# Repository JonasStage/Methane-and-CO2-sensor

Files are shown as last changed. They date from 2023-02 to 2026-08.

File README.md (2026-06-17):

# CH<sub>4</sub> and CO<sub>2</sub> DIY sensor with automated aeration

This repository is dedicated to CH<sub>4</sub> and CO<sub>2</sub> sensors created by Jonas Stage Sø, for more information see [(Sø et al., 2024)](https://doi.org/10.1029/2024JG008035) and [(Sø et al., 2023)](https://doi.org/10.1016/j.scitotenv.2023.162895).  
Sensors are made following [Bastviken et al. (2020)](https://doi.org/10.5194/bg-17-3659-2020), modified for automated fluxes, higher resolution, and lower power consumption by Jonas Stage Sø, University of Southern Denmark, Denmark.

## Repository structure

```
├── firmware/          Arduino sketches (normal run, no-pump, calibration, RTC setup)
├── hardware/          PCB files (Gerber, BOM, CPL, equipment list) and 3D-print STL
├── validation/        Sensor comparison data vs. Los Gatos Research instrument
├── docs/              Images and diagrams
└── CHANGELOG.md       Version history
```

## Table of contents

* [Latest version](#latest-version)
  * [Previous versions](#previous-versions)
* [Step-by-step guide](#a-step-by-step-guide-to-building-methane-and-co2-sensors-and-an-automated-floating-chamber)
  * [Ordering the PCB](#ordering-the-pcb)
  * [Building the sensor](#building-the-sensor)
  * [Flashing the code to the sensor](#flashing-the-code-to-the-sensor)
  * [Building the chamber](#building-the-chamber)
* [Calibrating the CO<sub>2</sub> sensor](#calibrating-the-co2-sensor)

---

## Latest version
Version 3 changes the backbone of the sensor:

* I've move away from the ATMEGA family, now the sensor is build around a RP2040 instead.
* The new RP2040 makes it easy to connect through USB-C, allowing to upload code and readout serial output through it.
* Even better resolution of the methane sensor, as the adc is now using differential input.
* Even fewer soldering points! Only 12 points needs to be soldered now.
* Minor improvements to layout and design.

### Previous versions
Version 2 brings several upgrades:

* The Arduino and datalogging shield from Version 3 are now integrated into a single PCB — fewer parts, lower cost.
* Switched from the NGM2611-E13 to the **Figaro TGS2611-E00** methane sensor. The TGS2611-E00 uses the SR-6 socket so the sensor can be replaced without soldering. Align the notch on the sensor with the footprint on the PCB. The methane sensor section have be broken off the PCB and soldered back to reduce overall height.
* Requires the **[MiniCore](https://github.com/MCUdude/MiniCore)** board package and a **USBASP ISP** programmer for uploading sketches.
* Three status LEDs:
  * **Power LED** — on whenever the sensor is powered
  * **SD LED** — blinks on every SD card write
  * **Status LED** — continuous light indicates an error (SD card, CO₂ sensor, SHT sensor, or ADC); blinks every 3 samples (6 s) when operating normally

See [CHANGELOG.md](CHANGELOG.md) for a summary of changes between versions.

---

## A step-by-step guide to building methane and CO<sub>2</sub> sensors and an automated floating chamber

> [!NOTE]
> Find all of this a bit too technical? Reach out to me and we can talk about collaborative possibilities at Jonassoe@biology.sdu.dk.

### Ordering the PCB 
A video of how to order the PCB (printed curcuit board) can be found here. Minor changes have been made to the gerber file since I created the video. 
Visit [JLCPCB](https://jlcpcb.com/) to order the PCB, this is done by uploading [`hardware/pcb/gerber.zip`](hardware/pcb/gerber.zip) and enabling PCB assembly with [`hardware/pcb/bom.csv`](hardware/pcb/bom.csv) and [`hardware/pcb/cpl.csv`](hardware/pcb/cpl.csv).<br><br>
Youtube Video (https://www.youtube.com/watch?v=w76-FkEEgp0)

### Building the sensor

1. Buy all items from the [equipment list](hardware/pcb/equipment_list.md). A soldering iron, flux pen, solder wire, and solder wick are also needed.
2. Solder four pin headers to the K33 ELG CO<sub>2</sub> sensor so the pins and screws align with the PCB footprint.
3. Install the coin-cell battery (CR1220) to power the real-time clock (RTC).
4. Insert the SD card (FAT32 format).
5. Now the sensor is ready to be flashed! 

### Flashing the code to the sensor 

1. Download and install [Thonny](https://thonny.org).
2. Connect the sensor to your computer via a USB-C cable. You should see the sensor show up as a hard drive on your computer.
3. Install MicroPython on the sensor. This can be done through Thonny or by drag-and-dropping the .uf2 file found [here](https://micropython.org/download/rp2-pico/rp2-pico-latest.uf2) onto the sensor drive.
  * To install MicroPython through Thonny follow these steps:
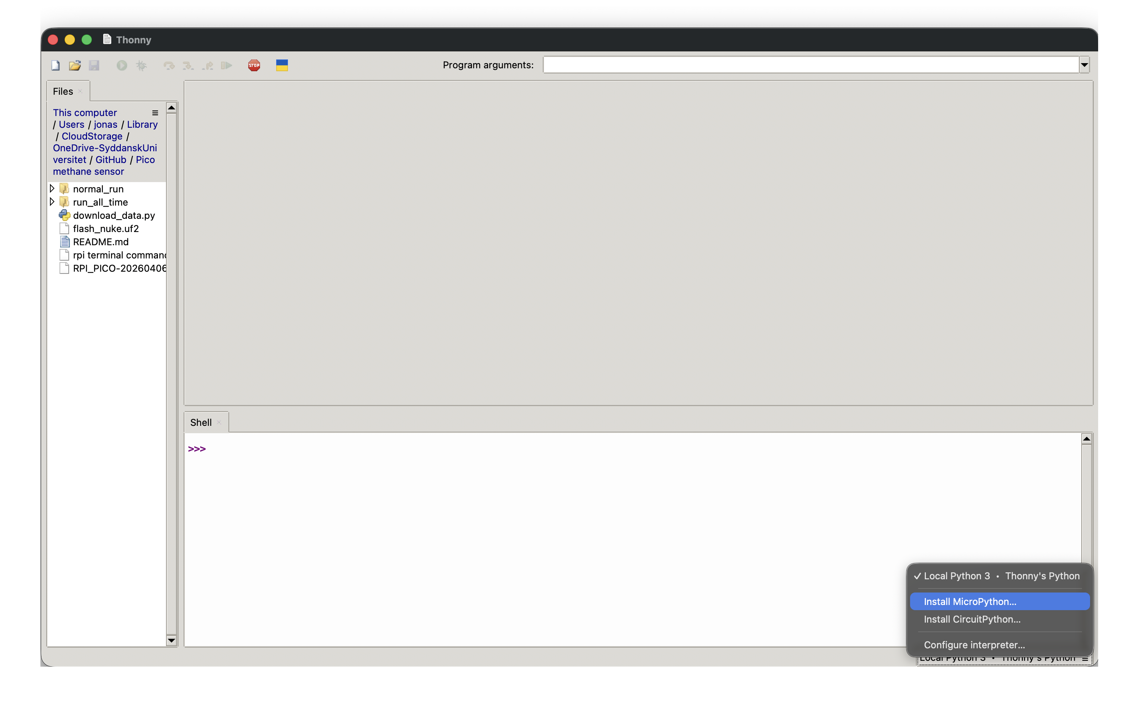
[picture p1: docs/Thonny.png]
    * In the bottom right corner press the text to open up the menu. <br>
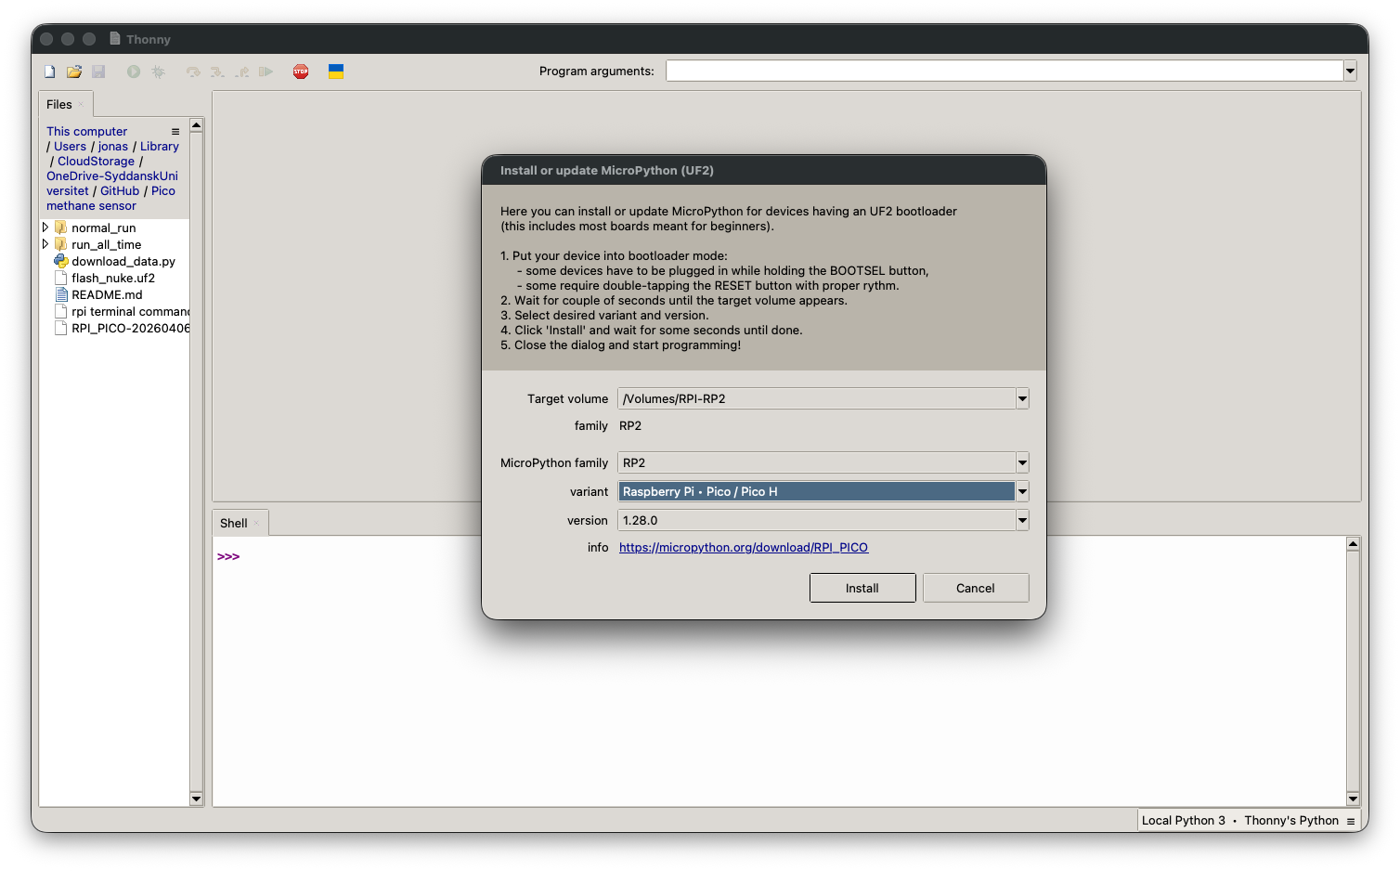
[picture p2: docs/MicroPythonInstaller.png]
    * Select the options as shown here. Currently the newest version is 1.28.0, but newer versions should also work. <br>
    * Install MicroPython by pressing 'Install'
4. The sensor will reboot, and you might have to press the 'Stop' button at the top to reconnect to it. 
5. If you haven't been using Thonny, now you have to. 
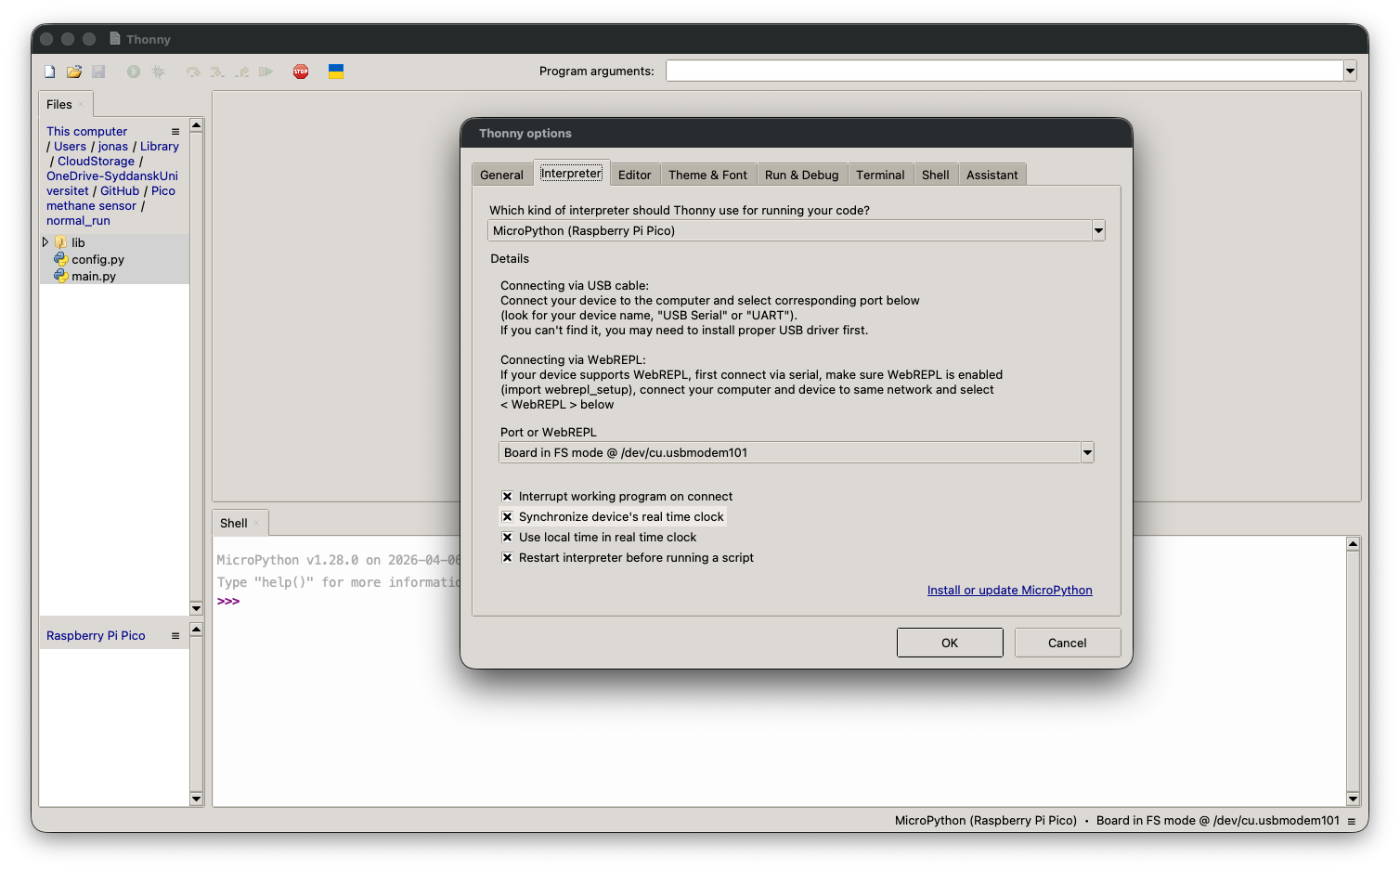
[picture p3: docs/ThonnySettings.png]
6. Ensure that 'Synchronize device's real time clock' is ticked in the settings menu. <br>
7. A new window will appear in the bottom left corner, with the title Raspberry Pi Pico.
8. Within Thonny locate the folder with the code you wish to upload. Usually it would be the [normal_run](firmware/normal_run/) code. 
9. Mark all the files in the folder 'Main.py', 'Config.py' and the 'lib' folder. 
10. Right click and choose 'Upload to /'.
11. The sensor will now automatically start when the sensor is powered on or you can run the program by opening the main.py and pressing the green arrow.
12. The sensor is now running. Note: the K33 CO<sub>2</sub> sensor requires at least 9 V — it will not respond when powered only through the USBASP ISP.
13. To read data, power off the sensor and open `datalog.csv` from the SD card.
14. For field deployment, connect a 12 V battery using a two-conductor wire. Observe correct polarity.

> [!WARNING]
> All Figaro CH₄ sensors must be calibrated to obtain the correct calibration coefficient. See [(Sø et al., 2024)](https://doi.org/10.1029/2024JG008035) for details.

### Building the chamber

* A 13.5 L bucket with a surface area of 0.0615 m² has been used. Adjust dimensions carefully — the sensor must not contact water.
* Wrap the outside of the bucket in aluminium foil tape to increase reflectance.
* Drill two holes on each side of the bucket at ~¾ of the depth from the top.
* Use two storage boxes (one inside, one outside the bucket). Drill aligned holes through both boxes and the bucket wall. Mount with screws, bolts, and an O-ring to prevent air exchange.
* Drill a small hole for fan wires and seal with silicone.
* Place the fan in the outer storage box and the sensor in the inner box. Connect the fan, observing polarity.
* Cut a 3 cm styrofoam sheet large enough to support the bucket, with a hole in the centre for the bucket. Attach with cable ties through holes drilled at the top of the bucket.
* The 3D-printed pump nozzle ([`hardware/3d_prints/pump_nozzle.stl`](hardware/3d_prints/pump_nozzle.stl)) connects the air pump outlet to the flexible tubing.

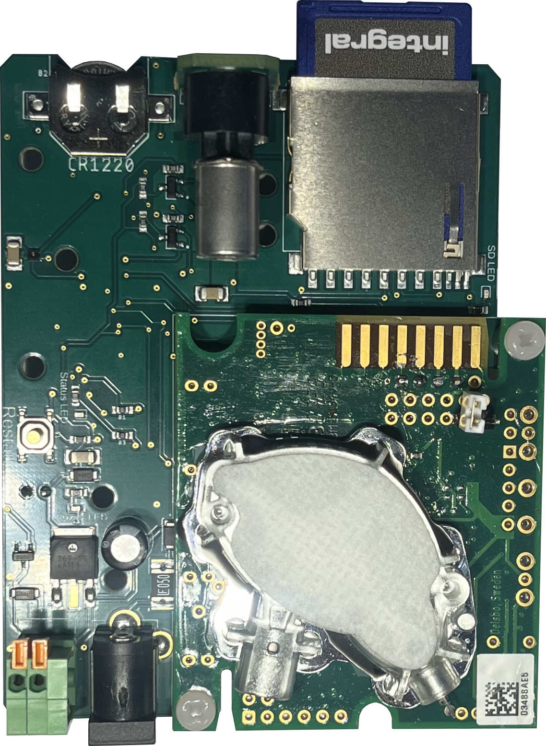
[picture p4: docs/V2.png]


---

## Calibrating the CO<sub>2</sub> sensor

The K33 ELG CO<sub>2</sub> sensor can be calibrated to 400 or 0 ppm by shorting two pins on the sensor. For details, see the [SenseAir K33 ELG product page](https://senseair.com/product/k33-elg/).

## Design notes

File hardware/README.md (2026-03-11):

# Hardware

| Folder | Contents |
|---|---|
| `pcb/` | Gerber file, BOM, CPL, and equipment list for ordering and assembling the PCB |
| `3d_prints/` | STL file for the 3D-printed pump-to-tubing nozzle connector |

## PCB ordering (JLCPCB)

1. Upload `pcb/gerber.zip` to [JLCPCB](https://jlcpcb.com/).
2. Enable **PCB Assembly** (both sides) and upload `pcb/bom.csv` and `pcb/cpl.csv`.
3. Tick **"Confirm Parts Placement"** before ordering.
4. Parts not available through JLCPCB (air pump, Figaro CH₄ sensor/connector, K33 CO₂ sensor) must be sourced separately — see [`pcb/equipment_list.md`](pcb/equipment_list.md).

## 3D prints

`3d_prints/pump_nozzle.stl` — connector between the air pump outlet and the flexible tubing of the floating chamber.

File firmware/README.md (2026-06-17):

# Firmware

Micropython code for the CH₄ and CO₂ sensor (Version 3).

| Folder  | Use |
|---|-----|
| `normal_run/`  | Standard deployment — measures for 40 min, vents chamber for 20 min, repeats |
| `run_all_time/` | Continuous logging without activating the pump |

## Board setup (MiniCore)

1. Install Thonny 
2. Connect the sensor via a USB-C cable.
3. Install MicroPython onto the sensor either through Thonny or by drag-and-dropping the .uf2 file found [here](https://micropython.org/download/rp2-pico/rp2-pico-latest.uf2) onto the sensor drive.
4. Transfer all the files from one of the code folders to the sensor through connecting in Thonny. This will also set the sensor clock according to the time of your computer.

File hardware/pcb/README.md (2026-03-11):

# PCB files

| File | Description |
|---|---|
| `gerber.zip` | Gerber files — upload to JLCPCB (or equivalent) to order the PCB |
| `bom.csv` | Bill of materials with JLCPCB part numbers |
| `cpl.csv` | Component placement list for automated assembly |
| `equipment_list.md` | Full equipment list with prices and supplier links |

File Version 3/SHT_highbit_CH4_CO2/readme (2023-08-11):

This folder is dedicated to the high-bit (16) version of CH4 and CO2 sensor with SHT temperature and humidity sensor.

Two of the folders contain similar code for the Arduino, however, the one starting with CAL is used when calibrating the sensors, whereas the other is used for measuring.

The last folder entitled PCB, contains the Gerber files, bill of materials (BOM) and component placement list (CPL), which are used when ordering printed circuit boards (PCB). In this example, the website JLCPCB has been used. By uploading the gerber file to JLCPCB and choosing PCB assembly you can then upload the BOM and CPL to automatic place the components. JLCPCB does not have the connector for the battery or air pump, Figaro CH4 sensor, K33 CO2 sensor, Adafruit data logger shield and Arduino, and thus these must be bought elsewhere.

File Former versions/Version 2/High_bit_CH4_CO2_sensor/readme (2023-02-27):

This folder is dedicated to the high bit (16) version of CH4 and CO2 sensor

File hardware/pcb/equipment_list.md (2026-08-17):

# Equipment list — Version 3

> Links are provided for reference; most items are available from multiple suppliers.
> The **Figaro methane sensor and connector** must be ordered through a Figaro distributor.
> The **K33 CO₂ sensor** must be ordered through a SenseAir distributor.

| Item | Qty | Price (€) | Part | Link | Notes |
|---|-----|---|---|---|---|
| 2 GB SD card | 1 | 10.70 | — | [RS Components](https://dk.rs-online.com/web/p/sd-kort/1805789) | |
| CO₂ sensor | 1 | 70.00 | K33-ELG SenseAir | [SenseAir](https://senseair.com/products/flexibility-counts/k33-elg/) | |
| Pin headers | 1 | 2.44 | — | [RS Components](https://dk.rs-online.com/web/p/printstiftlister/7666379) | To connect CO₂ sensor to PCB |
| Figaro methane sensor | 1 | 5.39 | TGS2611-E00 | [Figaro](https://www.figarosensor.com/product/entry/tgs2611-e00.html) | |
| Figaro connector | 1 | 1.74 | SR-6 | [Figaro](https://www.figarosensor.com/product/entry/sr6.html) | |
| Air pump | 1 | 18.60 | Orion ODB5515-12LB | [RS Components](https://dk.rs-online.com/web/p/blaesere/1444135/) | |
| PCB with components | 1 | ~15 | — | [JLCPCB](https://jlcpcb.com/) | Minimum order of 5 |
| Coin cell battery | 1 | 0.20 | CR1220 | [RS Components](https://dk.rs-online.com/web/p/knapcellebatterier/8660653) | Powers the RTC |
| Screw (M3) | 2 | 0.50 | — | [RS Components](https://dk.rs-online.com/web/p/maskinskruer/2326918) | Holds CO₂ sensor |
| Bolt (M3) | 2 | 0.30 | — | [RS Components](https://dk.rs-online.com/web/p/sekskantmotrikker/2326936) | Holds CO₂ sensor |
| Spacer | 2 | 0.40 | — | [RS Components](https://dk.rs-online.com/web/p/afstandsstykker/1363728) | Holds CO₂ sensor |
| Wire | — | 4.17 | — | [RS Components](https://dk.rs-online.com/web/p/styrekabel/0409258) | Rubber sheathing preferred; buy required length |
| Connector to battery | — | — | XT60 (suggested) | — | Optional; connects power cable to battery |
| USB-C cable | 1 | - | - | - | Should be able to do data transfer and not just power |
| 12 V battery | 1 | 168.30 | 12.8 V 12 Ah LiFePO4 | [RS Components](https://dk.rs-online.com/web/p/genopladelige-batteripakker/1828654) | Price varies with capacity |

**Total (without battery): ≈€130**
**Total (with battery): ≈€300**

> Prices may change over time.

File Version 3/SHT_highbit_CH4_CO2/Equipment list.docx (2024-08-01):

| Needed per sensor | € (euro) | | Link | Notes
Arduino uno rev 3 | 1 | 23.5 | Arduino uno | https://dk.rs-online.com/web/p/arduino/7154081/
Arduino uno datalogger shield | 1 | 18.9 | Adafruit Data Logger Shield | https://www.elfadistrelec.dk/da/samlet-datalogningsafskaermning-adafruit-1141/p/30091132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
2 GB SD card | 1 | 10.7 | | https://www.elfadistrelec.dk/da/sd-hukommelseskort-gb-transcend-ts2gsdc/p/11074864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
CO2 sensor | 1 | 70.0 | K33-ELG SenseAir | https://senseair.com/products/flexibility-counts/k33-elg/
Figaro methane sensor | 1 | 24.3 | NGM2611-E13 Figaro | https://dk.rs-online.com/web/p/miljosensor-ic-er/1346661
Air pump | 1 | 18.6 | Orion ODB5515-12LB | https://dk.rs-online.com/web/p/blaesere/1444135/ (https://eur03.safelinks.protection.outlook.com/?reserved=0)
PCB with components | 1 | 9.6 | | https://jlcpcb.com/ | A minimum of 5 must be bought.
Battery connector | 1 | 0.7 | Molex CGrid SL Srd Hdr RA 120 TPg Tin 2Ckt | https://dk.rs-online.com/web/p/printstiftlister/1790643
Air pump connector | 1 | 0.8 | Wurth Elektronik 4039 | https://dk.rs-online.com/web/p/printklemraekker/1917417
Pin headers | 1 | 1.0 | 1 row Straight Pin Header 5.7mm x 7.6mm | https://dk.rs-online.com/web/p/printstiftlister/2518339
Coin cell battery | 1 | 0.2 | RS Lithium Coin Cell CR1220 5PK | https://dk.rs-online.com/web/p/knapcellebatterier/8660653
Screw | 2 | 0.5 | to hold CO2 sensor | https://dk.rs-online.com/web/p/maskinskruer/2326918
Bolt | 2 | 0.3 | to hold CO2 sensor | https://dk.rs-online.com/web/p/sekskantmotrikker/2326936

Spacer

2

0.4

https://dk.rs-online.com/web/p/afstandsstykker/1363728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
Wire | 1.5 m | 5.9 | 2 core 22-30 AWG | https://dk.rs-online.com/web/p/styrekabel/0409258 | Rubber sheating is prefered for water, but any can do.
Wire crimp | 2 | 0.0 | SLTM Crimp Terminal, Series 70058, Female, with Tin (Sn) Plated Contact, 24-30 AWG, Reel | https://dk.rs-online.com/web/p/crimpkontakter/6706268
Socket connectors | 1 | | Socket connectors to connect PCB to datalogger shield | https://dk.rs-online.com/web/p/sil-fatninger/7022814
Battery | 1 | 168.3 | 12.8V 12Ah LiFePO4 battery | https://dk.rs-online.com/web/p/genopladelige-batteripakker/1828654?gb=b | Price depending on battery size. Here a standard 12 Ah battery is reported
Total no battery | | 194.64
Total | | 362.96

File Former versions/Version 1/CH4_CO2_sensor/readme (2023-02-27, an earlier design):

This folder is dedicated to the first version of CH4 and CO2 sensor

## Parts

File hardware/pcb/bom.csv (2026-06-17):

Comment | Designator | Footprint | JLCPCB Part #
100n | C3,C8 | C1206K | C24497
2.2_F | C23 | 0402-TIGHT | C12530
2.1mmDCbarrelJack | CN1 | DCJACK_2MM_PTH | C16214
MC33269DTRK-5.0G | IC1 | TO229P990X238-4N | C179577
PCF8523T | IC2 | SOIC8_150MIL | C2651516
10uF | C10 | 0805-NO | C440198
SDMMC06132 | U$1 | 6132 | C116683
27 | R6,R8 | 0402-TIGHT | C25100
StatusLED | D1,D5,D4 | LEDC1005X25N_FLAT-R | C375439
2N7002 | Q2 | SOT95P240X111-3N | C350313
K30FR | K33ELG2,K30FR1 | K30FR | C509262
Dontsoldermiddlepad | U$3 | CR1220 | C964818
DFLS1100-7 | D3,D7,D2,D6 | DIO_DFLS1100-7 | C107674
ABM8-272-T3 | Y2 | XTAL_ABM8-272-T3 | C20625731
100u | C6,C7 | E25-7 | C43805
1uF | C18,C21 | 0402-TIGHT | C52923
SHT45-AD1B-R2 | U$2 | SHT4X | C5221601
1k | R1,R3 | 0402-TIGHT | C11702
RP2040 | U5 | QFN-56 | C2040
B3U-1000P(M) | S3 | B3U-1000P(M) | C2934715
10nF | C25 | 402 | C15195
ADS1115 | U1 | MSOP10 | C37593
switch | S1 | TACTILE_SWITCH_SMD_5.2MM | C22459528
LP2985 | LP2985-33DBVR | SOT23-5 | C95414
0.1uF | C4,C11,C14,C15,C16,C17,C19,C20,C1,C2,C5 | 0402-TIGHT | C1525
PINHD-1X4 | J1 | 1X04 | C91552
1812L050PR | F1 | FUSM4632X75 | C151169
10k | R4,R7,R16 | 603 | C5123581
usbc | J6 | USB-C-16P-2LAYER-PADS | C165948
691403900002B | J2 | 691403900002B | C2898744
NX3215SA-32.768K-STD-MUA-14 | Y3 | XTAL_NX3215SA-32.768K-STD-MUA-14 | C156244
15pF | C22,C26 | 0402-TIGHT | C1548
W25Q128JVPIQ_TR | IC3 | SON127P600X500X80-9N | C190862
1uF | C9 | C1206K | C1848
12pF | C12,C13 | 402 | C1547
4050 | U2 | SOIC16 | C131932
470 | 10K.2,R2,R5 | 603 | C23179

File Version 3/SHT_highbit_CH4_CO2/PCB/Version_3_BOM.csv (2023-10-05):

Comment | Designator | Footprint | JLCPCB Part #
0.1uF | C2 C3 C4 | C1206K | C24497
0.33uF | C1 | C1206K | C274377
2N7002 | Q2 | SOT95P240X111-3N | C916396
10k | 10K.1 10K.2 10K.5 10K.6 10K.7 10K.8 10K.9 | 603 | C25804
20k | 20K1 | 603 | C4184
300 | R2 | 603 | C23025
1812L050PR | F1 | FUSM4632X75 | C151169
ADS1115 | U1 | MSOP10 | C37593
BSS138 | Q1 Q5 | SOT95P240X111-3N | C112239
DFLS1100-7 | D2 D3 | DIO_DFLS1100-7 | C107674
Linear voltage regulator | Q3 | DPAK228P998X235-3N | C79648
LED_RED | D4 | LEDC1005X25N_FLAT-R | C273598
SHT45-AD1B-R2 | U$2 | SHT4X | C5221601

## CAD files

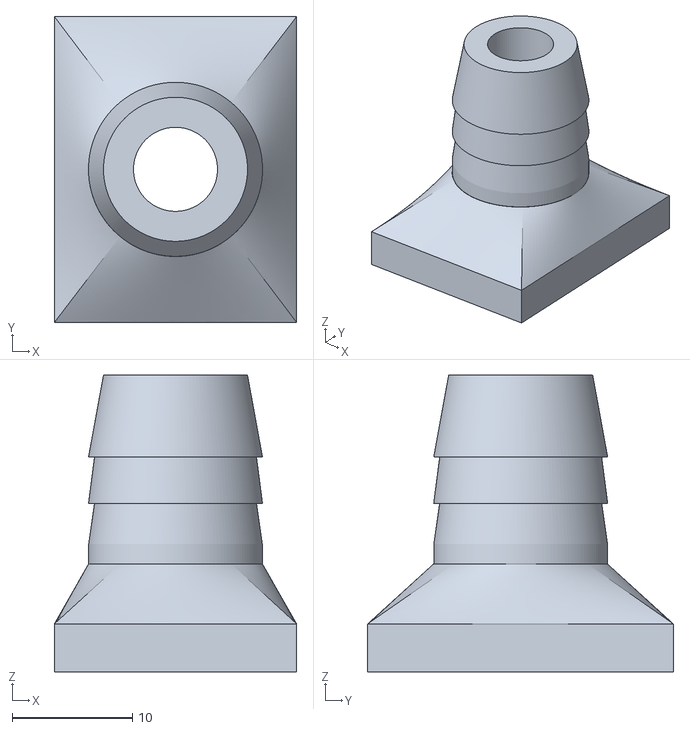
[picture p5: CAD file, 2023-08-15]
hardware/3d_prints/pump_nozzle.stl
20.2 x 25.5 x 24.7

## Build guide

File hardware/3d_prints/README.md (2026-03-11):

# 3D prints

`pump_nozzle.stl` — nozzle that connects the air pump outlet to the flexible tubing used to vent the floating chamber.

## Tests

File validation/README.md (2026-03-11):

# Sensor validation data

Comparison of DIY sensor measurements against a Los Gatos Research (LGR) commercial laser instrument.

| File | Contents |
|---|---|
| `diffusive_raw_data.csv` | Raw diffusive flux measurements |
| `diffusive_calculated_flux.csv` | Calculated diffusive fluxes |
| `bubbles_raw_data.csv` | Raw ebullitive (bubble) measurements |
| `bubbles_calculated_flux.csv` | Calculated ebullitive fluxes |
| `in-situ_raw_data.csv` | In-situ raw data |

See [Sø et al. (2024)](https://doi.org/10.1029/2024JG008035) for full methodology and results.

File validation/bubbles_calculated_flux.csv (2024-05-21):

DIY_bubble_concentration_diff | LGR_bubble_concentration_diff | datetime_start | datetime_end
104.68951334945427 | 96.533976 | 2024-03-20T12:44:20Z | 2024-03-20T12:44:58Z
101.35890933073907 | 89.44692 | 2024-03-20T12:49:39Z | 2024-03-20T12:51:13Z
216.9428151526719 | 210.9768 | 2024-03-20T12:55:05Z | 2024-03-20T12:56:19Z
225.2207478740806 | 204.25374000000002 | 2024-03-20T13:03:36Z | 2024-03-20T13:04:18Z
461.7038885712045 | 506.2368 | 2024-03-20T13:07:52Z | 2024-03-20T13:09:02Z
505.1624026826178 | 512.8510319999999 | 2024-03-20T13:18:07Z | 2024-03-20T13:19:29Z
493.2065584869556 | 488.87166 | 2024-03-20T13:26:04Z | 2024-03-20T13:26:54Z
924.8957216934185 | 990.1624799999998 | 2024-03-20T13:33:24Z | 2024-03-20T13:36:27Z
10.353751931130452 | 9.488651999999998 | 2024-03-20T11:34:21Z | 2024-03-20T11:37:03Z
5.1101605493388504 | 4.274759999999998 | 2024-03-20T11:39:05Z | 2024-03-20T11:40:49Z
6.318687798843051 | 4.954080000000001 | 2024-03-20T11:42:43Z | 2024-03-20T11:45:04Z
32.954251429849045 | 29.030639999999995 | 2024-03-20T11:47:12Z | 2024-03-20T11:50:42Z
48.02486653986939 | 42.785039999999995 | 2024-03-20T11:51:42Z | 2024-03-20T11:58:03Z
54.376238107563324 | 50.0934 | 2024-03-20T12:21:11Z | 2024-03-20T12:24:25Z
10.187368621762914 | 6.914400000000017 | 2024-03-20T12:32:05Z | 2024-03-20T12:34:08Z

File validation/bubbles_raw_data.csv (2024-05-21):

datetime | rh | tempC | DIY_CH4 | LGR_CH4 | LGR_CH4d
2024-03-20T11:06:45Z | 55.79 | 23.87 | 11.16781542633088 | 2.11043 | 2.15093
2024-03-20T11:06:46Z | NA | NA | NA | 2.12073 | 2.16439
2024-03-20T11:06:47Z | 55.97 | 23.88 | 11.34156579293697 | 2.1184 | 2.16205
2024-03-20T11:06:48Z | NA | NA | NA | 2.12014 | 2.16416
2024-03-20T11:06:49Z | 56.14 | 23.88 | 11.480486232376313 | 2.11688 | 2.16085
2024-03-20T11:06:50Z | NA | NA | NA | 2.12194 | 2.16628
2024-03-20T11:06:51Z | 56.38 | 23.88 | 11.648771794067292 | 2.11851 | 2.16274
2024-03-20T11:06:52Z | NA | NA | NA | 2.11947 | 2.16399
2024-03-20T11:06:53Z | 56.54 | 23.93 | 11.780802257154823 | 2.11761 | 2.16178
2024-03-20T11:06:54Z | NA | NA | NA | 2.11722 | 2.1618
2024-03-20T11:06:55Z | 56.72 | 23.94 | 11.912490797543908 | 2.11493 | 2.1593
2024-03-20T11:06:56Z | NA | NA | NA | 2.11571 | 2.16055
2024-03-20T11:06:57Z | 56.93 | 23.96 | 12.05408563031205 | 2.1132 | 2.15788
2024-03-20T11:06:58Z | NA | NA | NA | 2.11555 | 2.16046
2024-03-20T11:06:59Z | 57.09 | 23.96 | 12.196939727301837 | 2.11456 | 2.15958
2024-03-20T11:07:00Z | NA | NA | NA | 2.11335 | 2.15825
2024-03-20T11:07:01Z | 57.29 | 23.99 | 12.334529439853847 | 2.11358 | 2.15844
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

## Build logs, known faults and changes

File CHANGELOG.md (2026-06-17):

# Changelog

## Version 3 (Current version)
- Switched to RP2040 microcontroller.
- Added USB-C connection.
- The ADC now utilizes differential input, rather than single-ended.
- Fewer soldering points.
- Added QR-code to this GitHub.
- Minor improvements to layout and design.

## Version 2
- Merged Arduino + datalogging shield into single PCB — fewer parts, lower cost
- Switched methane sensor from NGM2611-E13 → TGS2611-E00 with SR-6 socket for easy replacement
- Added three status LEDs: Power, SD write activity, and error/status indicator
- Requires [MiniCore](https://github.com/MCUdude/MiniCore) board package and USBASP ISP programmer
- Power-optimised firmware (sleep modes, disabled SPI/USART during sleep)

## Version 1
- Added SHT temperature and humidity sensor (high-bit resolution)
- Separate Arduino + datalogging shield; separate PCB for sensors
- Higher-bit ADC resolution
- Initial Arduino shield design

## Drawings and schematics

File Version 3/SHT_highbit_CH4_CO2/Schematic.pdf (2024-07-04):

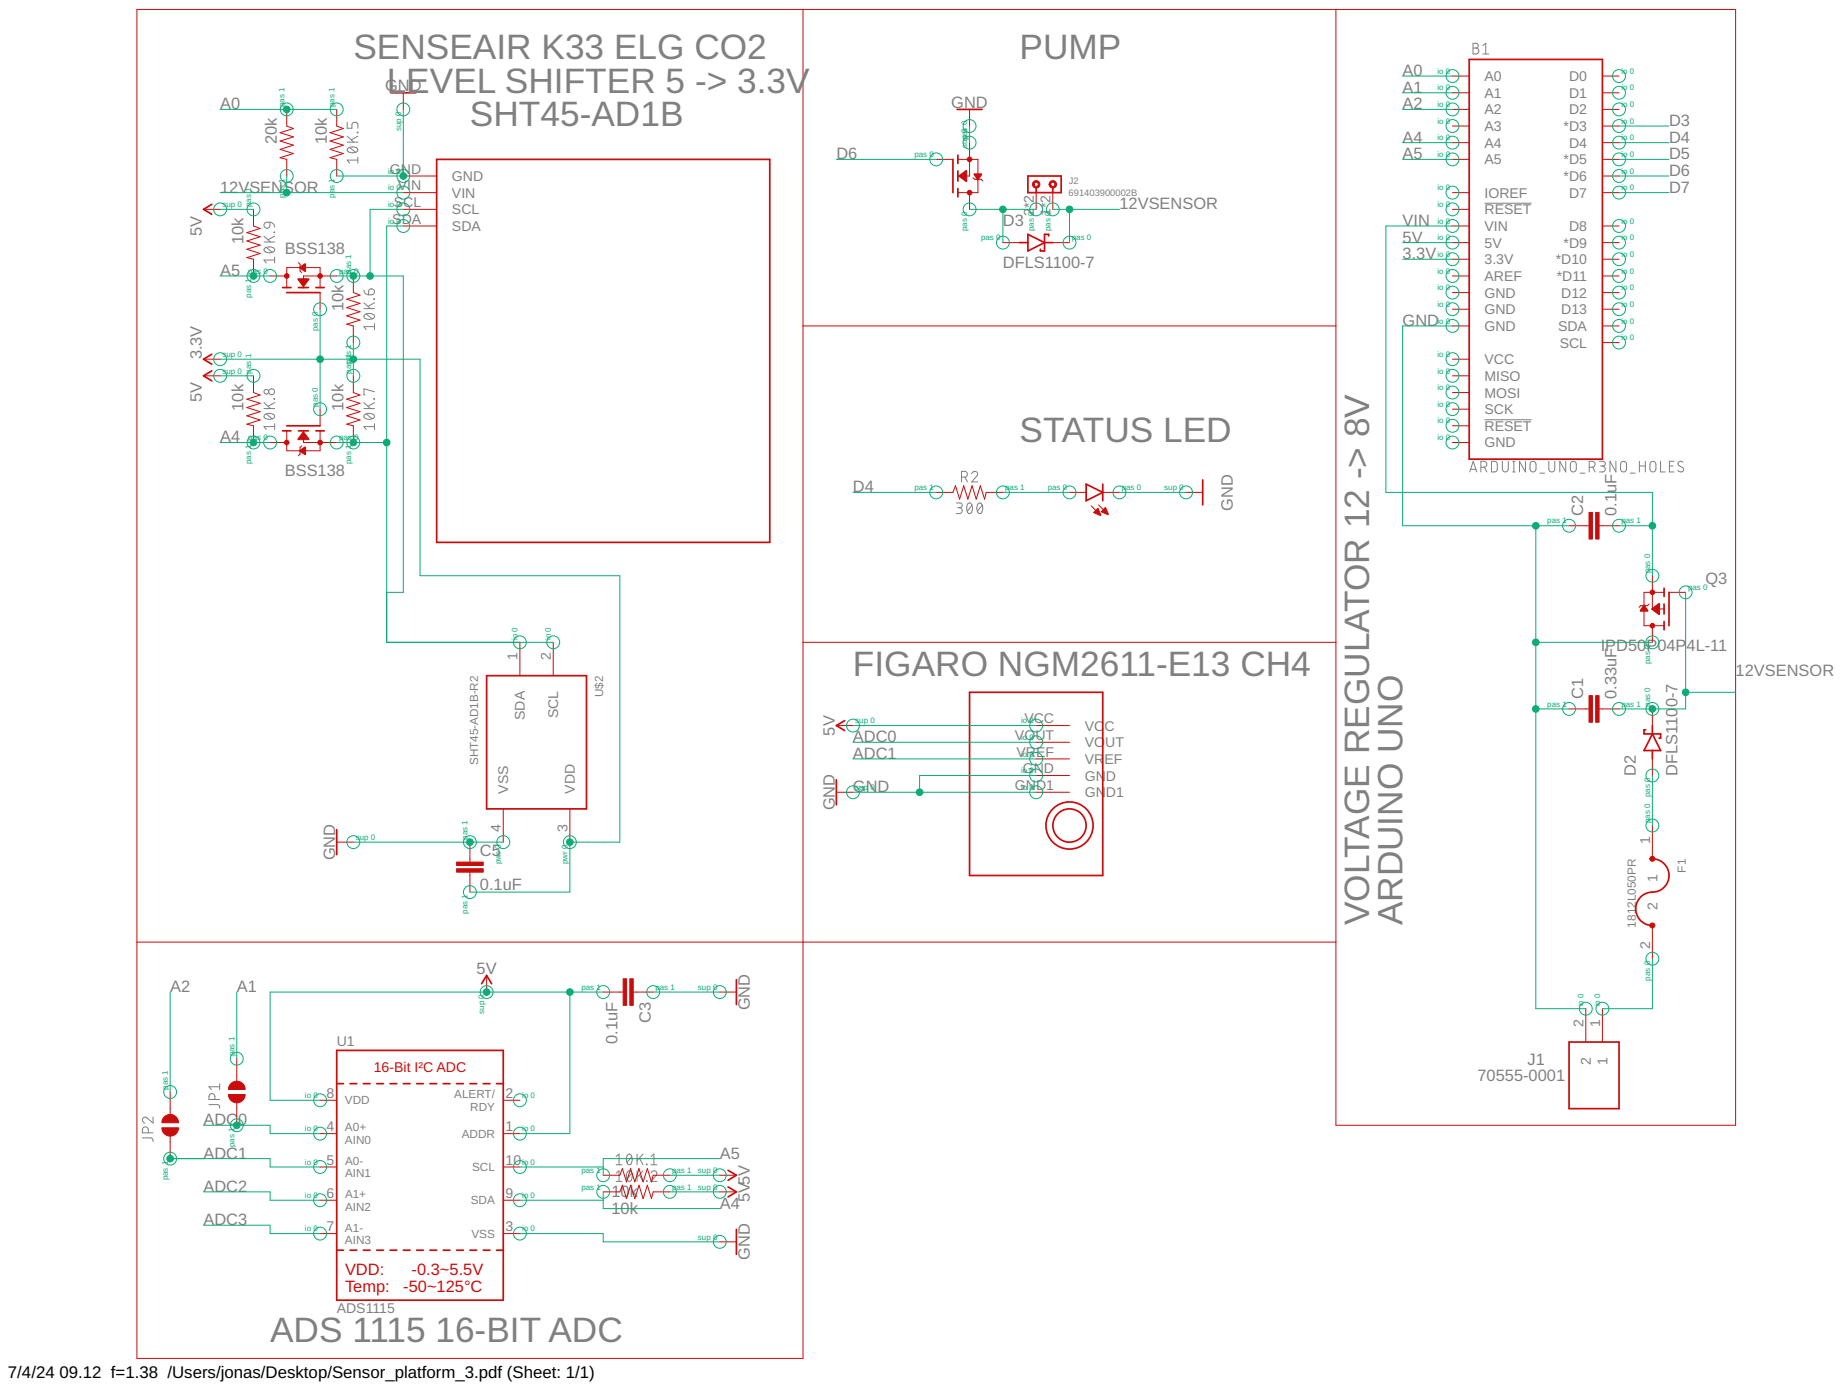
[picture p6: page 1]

pas 1 pas 1
sup 0

pas 0

7/4/24 09.12 f=1.38 /Users/jonas/Desktop/Sensor_platform_3.pdf (Sheet: 1/1)

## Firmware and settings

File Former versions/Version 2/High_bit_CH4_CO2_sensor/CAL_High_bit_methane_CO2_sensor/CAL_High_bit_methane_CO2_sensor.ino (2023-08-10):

// By David Bastviken and Nguyen Thanh Duc, Linkoping University, Sweden. 
// Modified for automated fluxes and lower power consumption by Jonas Stage Sø, University of Southern Denmark, Denmark.
// Thanks to cactus.io and Adafruit for code components. For setup of RTC, see separate logger shield documentation.
#include <SPI.h>
#include <Wire.h>
#include <RTClib.h>
#include "DHT.h"
#include <SdFat.h>
#include "Arduino.h"
#include <Adafruit_ADS1X15.h>
SdFat SD;

#define POWER_PIN 5                     // Used as a switch to turn sensors off when sleeping through D5 pin
int SampleNumber = 0 ;                  // Used for sample number in output file
int PumpCycle = 1 ;                     // Used for seperating pumpcycles 

int sleepCnt = 0;                       // Used for counting number of sleeping mills

/// Pump function
const byte PUMP_PIN = 6;                // Pump turned on and off through D6 pin

#define LOG_INTERVAL 2000               // Millisecond between logging entries (reduce to take more/faster data). milliseconds before writing the logged data permanently to disk. LOG_INTERVAL write each time (safest)
#define SYNC_INTERVAL 5000              // Millisecond between calls to flush() - to write data to the card

uint32_t syncTime = 0;                  // Time of last sync()
#define ECHO_TO_SERIAL   1              // If you want data to show in serial port
#define WAIT_TO_START    0              // Wait for serial input in setup()

#define dht_pin 7                       // DHT22 (RH_T) data pin. here D7 pin.
DHT dht;                                // Initialize DHT sensor for normal 16mhz Arduino.

#define Vb A0                           // Battery voltage. A0 pin
int CH4s = 0;                           // Variables used to store data
int CH4r = 0;                           // Variables used to store data
int Vbat = 0;                           // Variables used to store data
float CH4smV = 0;                       // Variables used to store data
float CH4rmV = 0;                       // Variables used to store data
float VbatmV = 0;                       // Variables used to store data                              
float mV = 5000;                        // Variables used to store data
float steps = 1024;                     // Variables used to store data

RTC_PCF8523 RTC;                        // define the Real Time Clock object

Adafruit_ADS1115 ads;

#define error_pin 4
#define running_pin 3

#define SD_CS_PIN 10                    // for the data logging shield, we use digital pin 10 for the SD cs line
File logfile;                           // the logging file

void error(char *str)                   // Halt if error
{
  Serial.print("error: ");
  Serial.println(str);
  digitalWrite(error_pin, HIGH); // red LED indicates error
  while (1); //halt command
}

double RHValue = 0;                     // Variables used to store data
double TempValue = 0;                   // Variables used to store data
double CO2Value = 0;                    // Variables used to store data
int co2Addr = 0x7F;                     // This is the modified address of the CO2 sensor, 7bits shifted left (defaul 0x68, but collide with RTC chip)

void wakeSensor() { 
  // This command serves as a wakeup to the CO2 sensor, for K33?ELG/BLG Sensors Only 
   
  // You'll have the look up the registers for your specific device, but the idea here is simple: 
  // 1. Disabled the I2C engine on the AVR 
  // 2. Set the Data Direction register to output on the SDA line 
  // 3. Toggle the line low for ~1ms to wake the micro up. Enable I2C Engine 
  // 4. Wake a millisecond. 
   
  TWCR &= ~(1<<2); // Disable I2C Engine 
  DDRC |= (1<<4); // Set pin to output mode 
  PORTC &= ~(1<<4); // Pull pin low 
  delay(1); 
  PORTC |= (1<<4); // Pull pin high again 
  TWCR |= (1<<2); // I2C is now enabled 
  delay(1);     
}
///////////////////////////////////////////////////////////////////
// Function : void initPoll()
// Executes : Tells sensor to take a measurement.
// Notes    : A fuller implementation would read the register back and
//            ensure the flag was set, but in our case we ensure the poll
//            period is >25s and life is generally good.
///////////////////////////////////////////////////////////////////
void initPoll() { 
 Wire.beginTransmission(co2Addr); 
 Wire.write(0x11); 
 Wire.write(0x00); 
 Wire.write(0x60); 
 Wire.write(0x35); 
 Wire.write(0xA6); 
  
 Wire.endTransmission(); 
 delay(20);  
 Wire.requestFrom(co2Addr, 2); 
   
 byte i = 0; 
 byte buffer[2] = {0, 0}; 

 while(Wire.available()) { 
     buffer[i] = Wire.read(); 
     i++; 
 }   
}

/////////////////////////////////////////////////////////////////// 
// Function : double readRH() 
// Returns  : The current RH Value, ?1 if error has occured 
/////////////////////////////////////////////////////////////////// 

double readRH() {
 int RH_value = 0;   // We will store the RH value inside this variable.  
 digitalWrite(13, HIGH);                
 
 ////////////////////////// 
 /* Begin Write Sequence */ 
 ////////////////////////// 
  
 Wire.beginTransmission(co2Addr); 
 Wire.write(0x22); //Command number 2 (Read Ram, 2 bytes)
 Wire.write(0x00); //Sensor address in ?? EEPROM ??
 Wire.write(0x14); //Two bytes starting from 0x14 (high byte) and 0x15 (low byte)
 Wire.write(0x36); //Checksum
  
 Wire.endTransmission(); 
 
 delay(20); 
 
 /////////////////////////   
 /* Begin Read Sequence */ 
 /////////////////////////  
   
 Wire.requestFrom(co2Addr, 4); 
   
 byte i = 0; 
 byte buffer[4] = {0, 0, 0, 0}; 
 
while(Wire.available()) { 
     buffer[i] = Wire.read(); 
     i++; 
 }   
   
 RH_value = 0; 
 RH_value |= buffer[1] & 0xFF;
 RH_value = RH_value << 8; 
 RH_value |= buffer[2] & 0xFF;
 Serial.print("RH  Data ");
 Serial.print(buffer[0], HEX);
 Serial.print("|"); 
 Serial.print(buffer[1], HEX);
 Serial.print("|");  
 Serial.print(buffer[2], HEX);
 Serial.print("|"); 
 Serial.println(buffer[3], HEX); 
 
 byte sum = 0;                              //Checksum Byte 
 sum = buffer[0] + buffer[1] + buffer[2];   //Byte addition utilizes overflow 
  
 if(sum == buffer[3]) { 
     // Success! 
     digitalWrite(13, LOW); 
     delay(10); 
     return ((double)RH_value / (double) 100); 
 }   
 else { 
  // Failure!  
  digitalWrite(13, LOW);
  delay(10);
  return ((double) -1); 
 }   
} 

/////////////////////////////////////////////////////////////////// 
// Function : double readTemp() 
// Returns  : The current Temperature Value, ?1 if error has occured 
/////////////////////////////////////////////////////////////////// 

double readTemp() {
 int Temp_value = 0;   // We will store the temperature value inside this variable.  
 digitalWrite(13, HIGH);                
 
 ////////////////////////// 
 /* Begin Write Sequence */ 
 ////////////////////////// 
  
 Wire.beginTransmission(co2Addr); //int K33 == 0x68
 Wire.write(0x22); //Command number 2 (Read Ram, 2 bytes)
 Wire.write(0x00); //Sensor address in ?? EEPROM ??
 Wire.write(0x12); //Two bytes starting from 0x12 (high byte) and 0x13 (low byte)
 Wire.write(0x34); //Checksum
  
 Wire.endTransmission(); 
 
 delay(20); 
 
  
 /////////////////////////   
 /* Begin Read Sequence */ 
 /////////////////////////  
   
 Wire.requestFrom(co2Addr, 4); 
   
 byte i = 0; 
 byte buffer[4] = {0, 0, 0, 0}; 
 
while(Wire.available()) { 
     buffer[i] = Wire.read(); 
     i++; 
 }   
   
 Temp_value = 0; 
 Temp_value |= buffer[1] & 0xFF;
 Temp_value = Temp_value << 8; 
 Temp_value |= buffer[2] & 0xFF;
 Serial.print("T   Data ");
 Serial.print(buffer[0], HEX);
 Serial.print("|"); 
 Serial.print(buffer[1], HEX);
 Serial.print("|");  
 Serial.print(buffer[2], HEX);
 Serial.print("|"); 
 Serial.println(buffer[3], HEX); 
 
 byte sum = 0;                              //Checksum Byte 
 sum = buffer[0] + buffer[1] + buffer[2];   //Byte addition utilizes overflow 
  
 if(sum == buffer[3]) { 
     // Success! 
     digitalWrite(13, LOW); 
     delay(10); 
     return ((double)Temp_value / (double) 100); 
 }   
 else { 
  // Failure!  
  digitalWrite(13, LOW);
  delay(10);
  return ((double) -1); 
 }   
} 


/////////////////////////////////////////////////////////////////// 
// Function : double readCO2() 
// Returns  : The current CO2 Value, ?1 if error has occured 
/////////////////////////////////////////////////////////////////// 

double readCO2() {
 int CO2_value = 0;   // We will store the temperature value inside this variable.  
 digitalWrite(13, HIGH);                
 
 ////////////////////////// 
 /* Begin Write Sequence */ 
 ////////////////////////// 
  
 Wire.beginTransmission(co2Addr); //int K33 == 0x68
 Wire.write(0x22); //Command number 2 (Read Ram, 2 bytes)
 Wire.write(0x00); //Sensor address in ?? EEPROM ??
 Wire.write(0x08); //Two bytes starting from 0x08 (high byte) and 0x09 (low byte). They contain the CO2 data
 Wire.write(0x2A); //Checksum
  
 Wire.endTransmission(); 
 
 delay(50); 
 
 /////////////////////////   
 /* Begin Read Sequence */ 
 /////////////////////////  
   
 Wire.requestFrom(co2Addr, 4); 
   
 byte i = 0; 
 byte buffer[4] = {0, 0, 0, 0}; 
 
while(Wire.available()) { 
     buffer[i] = Wire.read(); 
     i++; 
 }   
   
 CO2_value = 0; 
 CO2_value |= buffer[1] & 0xFF;
 CO2_value = CO2_value << 8; 
 CO2_value |= buffer[2] & 0xFF;
 Serial.print("CO2 Data ");
 Serial.print(buffer[0], HEX);
 Serial.print("|"); 
 Serial.print(buffer[1], HEX);
 Serial.print("|");  
 Serial.print(buffer[2], HEX);
 Serial.print("|"); 
 Serial.println(buffer[3], HEX); 
 
 byte sum = 0;                              //Checksum Byte 
 sum = buffer[0] + buffer[1] + buffer[2];   //Byte addition utilizes overflow 
  
 if(sum == buffer[3]) { 
     // Success! 
     digitalWrite(13, LOW); 
     delay(10); 
     return ((double)CO2_value * (double) 1); 
 }   
 else { 
  // Failure!  
  digitalWrite(13, LOW);
  delay(10);
  return ((double) -1); 
 }   
} 
  
void setup(void)
{
  pinMode(error_pin, OUTPUT);
  pinMode(running_pin, OUTPUT);
  pinMode(POWER_PIN, OUTPUT);
  pinMode(PUMP_PIN, OUTPUT); //Start pump
  Serial.begin(9600);
  Serial.println();
  dht.setup(dht_pin); //start RH_T_sensor
  RTC.begin(); 
  digitalWrite(POWER_PIN, HIGH);

    while (!Serial) {
    ;                              // wait for serial port to connect. Needed for native USB port only
  }

  Serial.print("Initializing SD card...");

  // see if the card is present and can be initialized:
  if (!SD.begin(SD_CS_PIN)) {
    error("Card failed, or not present");
    while(1);
  }
  Serial.println("card initialized.");

if (!ads.begin(0x49)) {
    error("Failed to initialize ADS.");
    while (1);
  }

  // connect to RTC
  Wire.begin();
  if (!RTC.begin()) {
    logfile.println("RTC failed");
#if ECHO_TO_SERIAL
    Serial.println("RTC failed");
#endif  //ECHO_TO_SERIAL
  } 

  if (! RTC.initialized()) {
    Serial.println("RTC is NOT running!");
    RTC.adjust(DateTime(F(__DATE__), F(__TIME__)));
    // following line sets the RTC to the date & time this sketch was compiled
    // This line sets the RTC with an explicit date & time, for example to set
    // January 21, 2014 at 3am you would call:
    // rtc.adjust(DateTime(2014, 1, 21, 3, 0, 0));
  }

  if (SD.exists("datalog.csv")) {
    Serial.println("datalog.csv exists.");
    File logfile = SD.open("datalog.csv", FILE_WRITE);
    logfile.close();
    Serial.println("millis,stampunix,datetime,RH%,tempC,CH4smV, CH4rmV, VbatmV, K33_RH, K33_Temp, K33_CO2, SampleNumber, PumpCycle");
} else {
    Serial.println("datalog.csv doesn't exist.");
    Serial.println("Creating datalog.csv...");
    logfile = SD.open("datalog.csv", FILE_WRITE);
    logfile.println("millis,stampunix,datetime,RH%,tempC,CH4smV, CH4rmV, VbatmV, K33_RH, K33_Temp, K33_CO2, SampleNumber, PumpCycle");
    logfile.close();
    Serial.println("millis,stampunix,datetime,RH%,tempC,CH4smV, CH4rmV, VbatmV, K33_RH, K33_Temp, K33_CO2, SampleNumber, PumpCycle");
}

digitalWrite(PUMP_PIN, HIGH); // Just to ensure the pump is functioning
delay(3000);
digitalWrite(PUMP_PIN, LOW);
Serial.println("Running calibration code");
}

char time_to_read_CO2 = 1;
char n_delay_wait = 0;


void loop() {
  DateTime now;
  digitalWrite(POWER_PIN, HIGH);

  SampleNumber++;

if ((SampleNumber % 9) == 0) {
  initPoll();
}

 if (time_to_read_CO2 == 1) {
    wakeSensor();
    delay(50);
    initPoll();
    delay(50);
    CO2Value = readCO2();
    delay(20);
    RHValue = readRH();
    delay(20);
    TempValue = readTemp();

    // if(RHValue >= 0) {
    //       Serial.print("RH: ");
    //       Serial.print(RHValue);
    //       Serial.print("% | Temp: ");
    //       Serial.print(TempValue);
    //       Serial.print("C | CO2: ");
    //       Serial.print(CO2Value, 0);
    //       Serial.println("ppm");
    //       Serial.println();
    // }
    // else {
    //       Serial.println(" | Checksum failed / Communication failure");
    // }
    time_to_read_CO2 = 0;
  }

  // delay for the amount of time we want between readings
  delay((LOG_INTERVAL - 1) - (millis() % LOG_INTERVAL));
 
  // log milliseconds since starting
  uint32_t m = millis();

#if ECHO_TO_SERIAL
  Serial.print(m);         // milliseconds since start
  Serial.print(", ");
#endif

  // fetch the time
  now = RTC.now();
  // log time
  logfile = SD.open("datalog.csv", FILE_WRITE);
  logfile.print(m);           // milliseconds since start
  logfile.print(", ");
  logfile.print(now.unixtime()); // seconds since 1/1/1970
  logfile.print(", ");
  //logfile.print('"');
  logfile.print(now.year(), DEC);
  logfile.print("/");
  logfile.print(now.month(), DEC);
  logfile.print("/");
  logfile.print(now.day(), DEC);
  logfile.print(" ");
  logfile.print(now.hour(), DEC);
  logfile.print(":");
  logfile.print(now.minute(), DEC);
  logfile.print(":");
  logfile.print(now.second(), DEC);
  logfile.close();
  //logfile.print('"');
#if ECHO_TO_SERIAL
  Serial.print(now.unixtime()); // seconds since 1/1/1970
  Serial.print(", ");
  //Serial.print('"');
  Serial.print(now.year(), DEC);
  Serial.print("/");
  Serial.print(now.month(), DEC);
  Serial.print("/");
  Serial.print(now.day(), DEC);
  Serial.print(" ");
  Serial.print(now.hour(), DEC);
  Serial.print(":");
  Serial.print(now.minute(), DEC);
  Serial.print(":");
  Serial.print(now.second(), DEC);
  //Serial.print('"');
#endif //ECHO_TO_SERIAL
float rh,temp;
  // Reading temperature or humidity takes about 250 milliseconds.
  // Sensor readings may also be up to 2 seconds 'old' (its a slow sensor)
rh = dht.getHumidity();
temp = dht.getTemperature();
  // Check if any reads failed and exit early (to try again).
  if (!dht.getStatusString() == "OK") {
    error("DHT fejl");
    return;
  }
int16_t adc0, adc1, adc2, adc3 = 0;
  float volts0, volts1, volts2, volts3 = 0;

  delay(100);
  adc0 = ads.readADC_SingleEnded(0);
  delay(100);
  adc1 = ads.readADC_SingleEnded(1);
  delay(100);
  CH4smV = ads.computeVolts(adc0)*1000;
  CH4rmV = ads.computeVolts(adc1)*1000;
  delay(100);
  Vbat = analogRead(Vb); //read CH4 Vref
  VbatmV = Vbat * (mV / steps); //convert pin reading to mV, NOT YET correcting for the voltage divider.

  logfile = SD.open("datalog.csv", FILE_WRITE);
  logfile.print(", ");
  logfile.print(rh);
  logfile.print(", ");
  logfile.print(temp);
  logfile.print(", ");
  logfile.print(CH4smV);
  logfile.print(", ");
  logfile.print(CH4rmV);
  logfile.print(", ");
  logfile.print(VbatmV);

  logfile.print(", ");
  logfile.print(RHValue);
  logfile.print(", ");
  logfile.print(TempValue);
  logfile.print(", ");
  logfile.print(CO2Value);
  logfile.print(", ");
  logfile.print(SampleNumber);
  logfile.print(", ");
  logfile.print(PumpCycle);
  logfile.println();
  logfile.close();
#if ECHO_TO_SERIAL
  Serial.print(", ");
  Serial.print(rh);
  Serial.print(", ");
  Serial.print(temp);
  Serial.print(", ");
  Serial.print(CH4smV);
  Serial.print(", ");
  Serial.print(CH4rmV);
  Serial.print(", ");
  Serial.print(VbatmV);
  Serial.print(", ");
  Serial.print(RHValue);
  Serial.print(", ");
  Serial.print(TempValue);
  Serial.print(", ");
  Serial.print(CO2Value);
  Serial.print(", ");
  Serial.print(SampleNumber);
  Serial.print(", ");
  Serial.print(PumpCycle);

#endif //ECHO_TO_SERIAL

#if ECHO_TO_SERIAL
  Serial.println();
#endif // ECHO_TO_SERIAL

if ((SampleNumber % 3) == 0) {
    digitalWrite(running_pin, HIGH);
    delay(10);
    digitalWrite(running_pin, LOW);
}

  if (time_to_read_CO2 == 0 ) {
    if (n_delay_wait < 9)
      n_delay_wait ++;
    else {
      time_to_read_CO2 = 1;
      Serial.print("Time to read K33 sensor: ");
      n_delay_wait = 0;
    }
  }


 
  // Now we write data to disk! Don't sync too often - requires 2048 bytes of I/O to SD card
  // which uses power and takes time
  if ((millis() - syncTime) < SYNC_INTERVAL) return;
  syncTime = millis();
  logfile.flush();  

}

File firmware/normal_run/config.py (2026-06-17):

"""
Configuration for Pico Methane Sensor
Pin assignments and timing constants for Raspberry Pi Pico.
"""

# === I2C Bus (shared by SHT4x, ADS1115, PCF8523, K33) ===
I2C_ID = 0
I2C_SDA_PIN = 0   # GP0
I2C_SCL_PIN = 1   # GP1
I2C_FREQ = 100_000

# === SPI Bus (SD Card) ===
SPI_ID = 0
SPI_SCK_PIN = 2   # GP2
SPI_MOSI_PIN = 3  # GP3
SPI_MISO_PIN = 4  # GP4
SD_CS_PIN = 5     # GP5
SD_CD_PIN = 12    # GP12 - SD card detect (input)

# === GPIO ===
PUMP_PIN = 25      # GP25 - Pump relay/MOSFET control
LED_PIN = 11       # GP11 - Status LED

# === I2C Addresses ===
SHT4X_ADDR = 0x44
ADS1115_ADDR = 0x49
PCF8523_ADDR = 0x68
K33_ADDR = 0x7F

# === Timing (milliseconds) ===
LOG_INTERVAL_MS = (2*1000)           # Time between data logging entries. Set to every 2 seconds.
MEASUREMENT_LENGTH_MS = (40*60*1000) # Length of measurements before going to sleep (40 min). Change 40 to the number of minutes you want the sensor to measure for
SLEEP_CYCLE_MS = (20*60*1000)  		 # Duration the sensor sleeps with pump turned on (20 min). Change 20 to the number of minutes you want the sensor to sleep for

# === Data Buffering ===
WRITE_BUFFER_SIZE = 10  # Number of samples to accumulate in RAM before writing to SD

# === K33 CO2 Sensor ===
K33_READ_INTERVAL = 10  # Read K33 every N logging cycles

# === ADC ===
ADC_VREF_MV = 3300.0   # Pico ADC reference voltage (3.3V)
ADC_STEPS = 65535.0     # Pico 16-bit ADC (read_u16 returns 0-65535)

# === Data File ===
DATA_FILENAME = "datalog.csv"
CSV_HEADER = "millis,stampunix,datetime,RH,tempC,CH4mV,K33_RH,K33_Temp,K33_CO2,SampleNumber,PumpCycle"

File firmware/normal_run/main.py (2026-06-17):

"""
Pico Methane Sensor — Main Script
Ported from Arduino (AVR) to MicroPython for Raspberry Pi Pico.

Reads CH4 (via ADS1115), CO2/RH/Temp (via K33), SHT4x temp/humidity,
battery voltage, and logs data to CSV on SD card. Includes pump cycling
with low-power lightsleep between measurement periods.

On boot, syncs the PCF8523 RTC from the host computer's time (via
machine.RTC, which Thonny sets automatically on connect).
Headless boots use the battery-backed PCF8523 time directly.

Authors:
  - David Bastviken & Nguyen Thanh Duc, Linköping University, Sweden
  - Jonas Stage Sø, University of Southern Denmark (Pico port & automation)
"""

import machine
import time
import os
import sys

import config
from lib.sht4x import SHT4x
from lib.ads1115 import ADS1115
from lib.pcf8523 import PCF8523
from lib.k33 import K33
from lib.sdcard import SDCard

# ── Hardware Initialization ──────────────────────────────────────────────────

i2c = machine.I2C(
    config.I2C_ID,
    sda=machine.Pin(config.I2C_SDA_PIN),
    scl=machine.Pin(config.I2C_SCL_PIN),
    freq=config.I2C_FREQ,
)

machine.Pin(config.SPI_MISO_PIN, machine.Pin.IN, machine.Pin.PULL_UP)
spi = machine.SPI(
    config.SPI_ID,
    baudrate=1_000_000,
    polarity=0,
    phase=0,
    sck=machine.Pin(config.SPI_SCK_PIN),
    mosi=machine.Pin(config.SPI_MOSI_PIN),
    miso=machine.Pin(config.SPI_MISO_PIN),
)
sd_cs = machine.Pin(config.SD_CS_PIN, machine.Pin.OUT, value=1)
sd_cd = machine.Pin(config.SD_CD_PIN, machine.Pin.IN, machine.Pin.PULL_UP)

pump_pin = machine.Pin(config.PUMP_PIN, machine.Pin.OUT, value=0)
led_pin  = machine.Pin(config.LED_PIN,  machine.Pin.OUT, value=0)


# ── Sensor Objects ───────────────────────────────────────────────────────────

def init_sensors():
    """Initialize all sensors except RTC. Returns (sht, ads, k33_sensor, sd_mounted)."""
    errors = []

    try:
        sht = SHT4x(i2c, config.SHT4X_ADDR)
        print("SHT4x initialized.")
    except Exception as e:
        sht = None
        errors.append("SHT4x: {}".format(e))

    try:
        ads = ADS1115(i2c, config.ADS1115_ADDR, gain=1)
        print("ADS1115 initialized.")
    except Exception as e:
        ads = None
        errors.append("ADS1115: {}".format(e))

    try:
        k33_sensor = K33(i2c, config.I2C_SDA_PIN, config.K33_ADDR,
                         scl_pin_num=config.I2C_SCL_PIN, freq=config.I2C_FREQ)
        print("K33 CO2 sensor initialized.")
    except Exception as e:
        k33_sensor = None
        errors.append("K33: {}".format(e))

    class _RP2SDCard(SDCard):
        def init_spi(self, baudrate):
            pass

    sd_mounted = False
    sd = None
    print("Initializing SD card... (CD pin = {})".format(sd_cd.value()))
    time.sleep_ms(250)
    try:
        sd = _RP2SDCard(spi, sd_cs)
        print("SD init OK, sectors={}".format(sd.sectors))
    except Exception as e:
        errors.append("SD init: {}".format(e))
    if sd is not None:
        try:
            buf = bytearray(512)
            sd.readblocks(0, buf)
            print("SD readblocks OK")
        except Exception as e:
            errors.append("SD readblocks: {}".format(e))
        try:
            os.mount(sd, "/sd")
            sd_mounted = True
            print("SD card mounted at /sd")
        except Exception as e:
            errors.append("SD mount: {}".format(e))

    if errors:
        for err in errors:
            print("WARNING: " + err)
        led_pin.value(1)

    return sht, ads, k33_sensor, sd_mounted


# ── RTC Setup ────────────────────────────────────────────────────────────────

def _rtc_time_valid(y, mo, d, h, mi, s):
    return (2024 <= y <= 2099 and 1 <= mo <= 12 and 1 <= d <= 31
            and 0 <= h <= 23 and 0 <= mi <= 59 and 0 <= s <= 59)


def setup_rtc(rtc):
    """Sync PCF8523 from Thonny-synced machine.RTC, or read stored time on headless boot."""
    if rtc is None:
        print("ERROR: RTC not available.")
        return

    # Path 1: Thonny synced machine.RTC — forward it to PCF8523
    internal = machine.RTC()
    y, mo, d, wd, h, mi, s, _ = internal.datetime()
    print("Internal RTC: {}/{}/{} {:02d}:{:02d}:{:02d}".format(y, mo, d, h, mi, s))

    if _rtc_time_valid(y, mo, d, h, mi, s):
        pcf_wd = (wd + 1) % 7  # MicroPython Mon=0 → PCF8523 Sun=0
        rtc.set_time(y, mo, d, pcf_wd, h, mi, s)
        print("RTC synced from host: " + rtc.datetime_str())
        return

    # Path 2: No host time — read PCF8523 directly (headless boot)
    for attempt in range(5):
        time.sleep_ms(200)
        try:
            if not rtc.initialized():
                print("PCF8523 oscillator not running (attempt {})".format(attempt + 1))
                continue
            ry, rmo, rd, _, rh, rmi, rs = rtc.now()
            if _rtc_time_valid(ry, rmo, rd, rh, rmi, rs):
                print("RTC is running: " + rtc.datetime_str())
                return
            print("PCF8523 invalid time: {}/{}/{} {:02d}:{:02d}:{:02d}".format(
                ry, rmo, rd, rh, rmi, rs))
        except Exception as e:
            print("PCF8523 error (attempt {}): {}".format(attempt + 1, e))

    print("No valid RTC time. Timestamps will be N/A.")


# ── Data Logging ─────────────────────────────────────────────────────────────

def ensure_csv(sd_mounted):
    print(config.CSV_HEADER)
    if not sd_mounted:
        return
    filepath = "/sd/" + config.DATA_FILENAME
    try:
        os.stat(filepath)
        print("{} exists.".format(config.DATA_FILENAME))
    except OSError:
        print("Creating {}...".format(config.DATA_FILENAME))
        with open(filepath, "w") as f:
            f.write(config.CSV_HEADER + "\n")
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

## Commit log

2022-04-27 Add files via upload
    A GHG sensor system using Arduino Uno rev3, figaro methane sensor, K33 ELG CO2 sensor, DHT22 temperature and humidity sensor and a 12V pump.
    Originally an idea from Bastviken et al. (2020), while this didn't contain the pump, and was less power efficient.
    [Methane_CO2_sensor.ino]
2022-04-27 Add files via upload
    As the main file, however this time a MAX31865 op-amp was used to readout data from a PT1000 temperature sensor.
    Furthermore, a 16-bit ADC was added to readout methane sensors.
2023-02-27 PCB added
2023-03-24 Removal of var POWER_PIN
    Power_pin not used in this setup
2023-08-11 update ignored files
    [all_sensor_model_coef.csv]
2023-08-11 updated structure
    [Version_3_BOM.csv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]
2023-08-15 Create Pump nozzle.stl
    [Pump nozzle.stl]
2023-10-05 Changed parts and position
    Changed one capacitor which was different from the remaining, thus reducing number of different parts and price
    [Version_3_BOM.csv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]
2023-11-24 Remove duplicate libraries, added materials list, and a now pump sensor sketch
2024-01-05 Changes to positioning of parts
    [Version_3_CPL.csv]
2024-05-21 Added data comparing the figaro sensor with an Los Gatos Research instrument
    [bubbles_calculated_flux.csv, bubbles_raw_data.csv, diffusive_calculated_flux.csv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]
2026-03-11 Version 4
    [Version_3_BOM.csv, bom.csv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]
2026-03-11 Spring cleaning
    [Pump nozzle.stl]
2026-03-11 Update readme.md with detailed descriptions of codes
    Expanded explanations for Calibration, No_pump_code, and Normal_run_code.
2026-03-11 Update links in readme.md for Arduino codes
2026-03-11 Update Calibration code link in readme.md
2026-03-11 Update README with video plans and calibration info
    Added a note about creating an assembly video and included calibration instructions for the CO2 sensor.
2026-03-11 Fix wording in README regarding sensor assembly video
    Corrected wording from 'of how' to 'on how' in the README.
2026-03-11 Document version 4 upgrades and installation steps
    Added details about version 4 of the sensor, including upgrades, new components, and installation instructions.
2026-03-11 Update Arduino tools.png
2026-03-11 Update README with table of contents and version details
    Added a table of contents and updated sections for the latest version of the sensor, including detailed assembly instructions and calibration information.
2026-03-11 Update README with calibration warning and connection details
    Added a warning about sensor calibration and clarified battery connection instructions.
2026-03-11 Restructure repository for clarity and navigability
    Top-level layout:
    firmware/ - Arduino sketches (flattened from Version 4/Arduino code/**/**/)
    hardware/ - PCB files + 3D print STL (flattened from Version 4/PCB/ and
    Pump to hose 3D connector/)
    libraries/ - README with Library Manager links (replaces 7 zip bundles)
    validation/ - LGR comparison CSVs (renamed from verbose folder name)
    docs/ - Images (Arduino_tools.png, V4.png)
    archive/ - Previous versions (v1/v2/v3/swimmer, flattened nesting)
    CHANGELOG.md - New: version history
    Key changes:
    - Removed all library zip files; libraries/README.md lists them with
    Arduino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
    [bom.csv, bubbles_calculated_flux.csv, bubbles_raw_data.csv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]
2026-03-11 Revise methane sensor and CO2 calibration instructions
    Updated details about the methane sensor and calibration process.
2026-03-26 Update README with flashing instructions for sensor
    Added instructions for flashing code onto the sensor using both SensorUploader and Arduino IDE.
2026-04-01 Update gerber.zip
    Minor changes to the gerber file
2026-04-01 Add PCB ordering instructions to README
    Added a section on ordering the PCB with instructions and a video link.
2026-04-01 Updated files
    [pump_nozzle.stl]
2026-04-01 Revise Windows driver installation instructions
    Updated instructions for installing drivers on Windows, specifying libusbK and Libusb-win32, and added steps for using Zadig.
2026-04-01 Update SensorUploader to support windows 11 and 10.
2026-04-01 Specify FAT32 format for SD card insertion
    Clarify SD card format requirement in instructions.
2026-04-09 Update equipment list to replace M2 with M3 screws and bolts
2026-04-29 Remove SensorUploader instructions from README
    Removed detailed instructions for using SensorUploader.jar and retained Arduino IDE instructions.
2026-06-17 Minor updates
    [pump_nozzle.stl]
2026-06-17 Version 3 now out!
    Version 3 is now live.
    Check the changelog for details.
    [bom.csv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]
2026-08-17 Update pin headers price and link in equipment list
    Updated the price and link for pin headers in the equipment list.
